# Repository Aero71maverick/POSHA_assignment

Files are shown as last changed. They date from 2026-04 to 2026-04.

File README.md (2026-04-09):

# POSHA Systems Engineering Internship Assignment

**Kunal Paroda** · Roll No: 24B0071  
2nd Year, B.Tech. Aerospace Engineering — IIT Bombay  
Submitted to: POSHA Engineering Team · April 9, 2026

---

## Overview

This repository contains the complete submission for the POSHA Systems Engineering internship assignment, covering three interconnected tasks around servo motor testing, reliability analysis, and robot system design.

| Task | Title |
|---|---|
| Task 1 | Servo Motor QC Jig Design |
| Task 2 | Servo System Reliability & Safety Analysis |
| Task 3 | POSHA System Design Improvements |

---

## Task 1: Servo Motor QC Jig Design

A custom quality-control test jig designed to characterise servo motors — primarily the **Dynamixel XL430-W250-T** — across their full operating envelope: stall torque, no-load speed, efficiency, and current draw at multiple supply voltages.

### Key Design Decisions

- **Target servo:** Dynamixel XL430-W250-T (1.5 N·m stall @ 12 V, 4096 counts/rev absolute encoder, TTL serial bus)
- **Load mechanism:** JGA25-370 DC gear motor with PI current-control loop for precise, commanded torque
- **Frame:** Aluminium 2020 T-slot extrusion (vs. DIN rail) — adjustable, corrosion-resistant, handles stall reaction loads
- **Torque measurement:** Dual load cells (HX711, 24-bit ADC) in a differential configuration that cancels gravitational bias
- **Speed/position:** AS5600 magnetic rotary encoder (12-bit, contactless, I²C)
- **Controller:** Arduino Uno (5 V native — avoids 3.3 V compatibility issues with HX711, ACS712, and servo signal lines)

### CAD Model & Assembly

The full jig was designed in **Fusion 360** as a parametric, jointed assembly. All components are linked by kinematic joints — not just static positions — so the gear mesh, encoder sweep, and reaction arm deflection can all be verified in simulation before physical assembly.

**📹 CAD Joint Motion Video** — click to watch on YouTube:

Fusion 360 Kinematic Demo (https://youtu.be/AN1cJzH8ZRU)
*Full kinematic chain: gear mesh → encoder magnet sweep → load cell arms deflecting.*

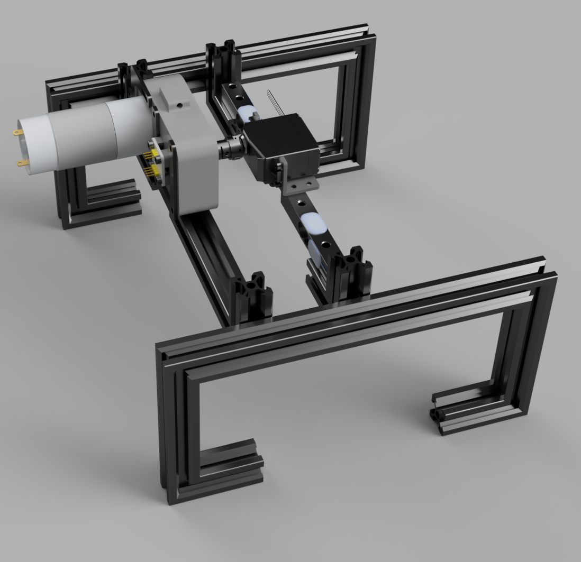
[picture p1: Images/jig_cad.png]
Jig Assembly Isometric

*Full jig assembly at nominal position.*

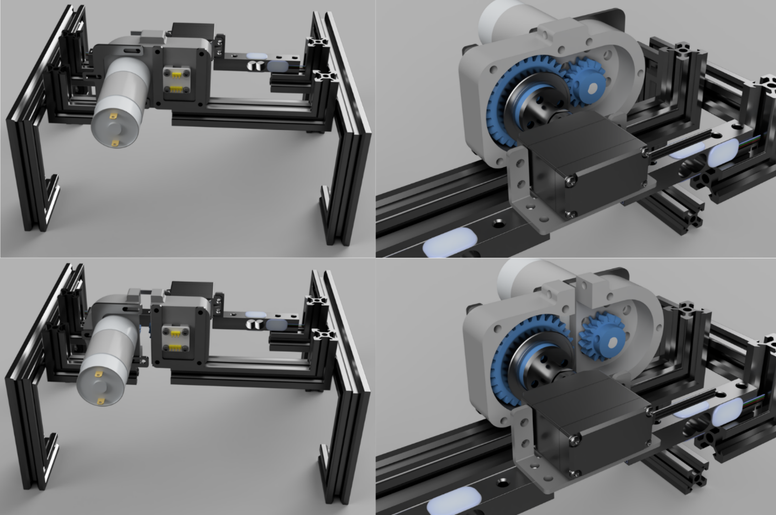
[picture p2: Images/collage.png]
No-Load Configuration

*Motor-side gearbox half disengaged — no-load test configuration.*

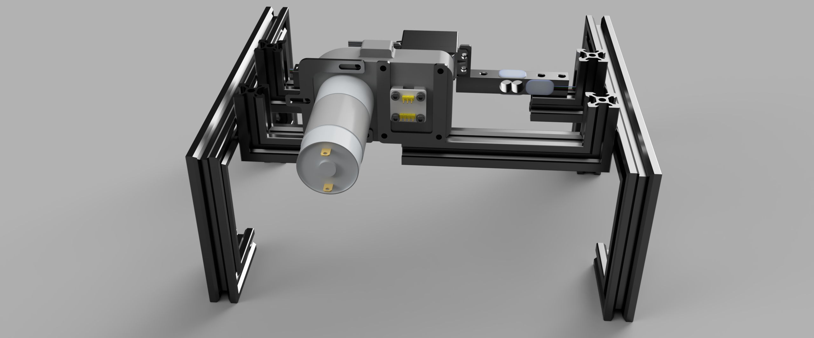
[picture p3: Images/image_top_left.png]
Top Left View

*Top-left view of jig assembly.*

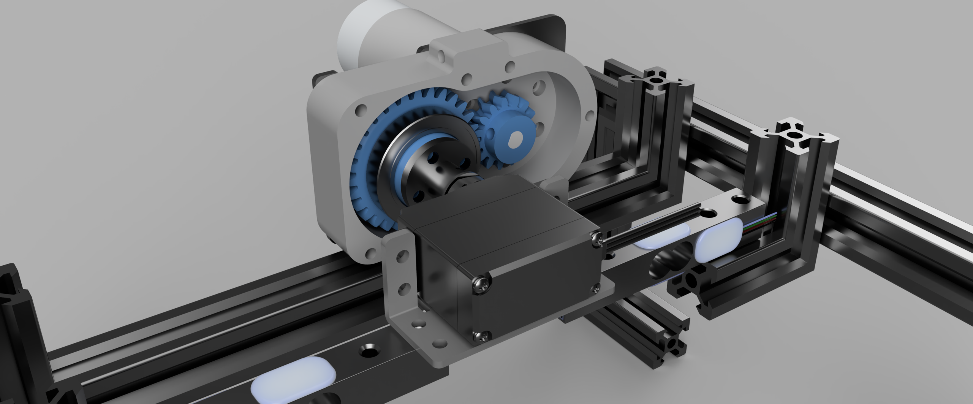
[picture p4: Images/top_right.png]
Top Right View

*Top-right view of jig assembly.*

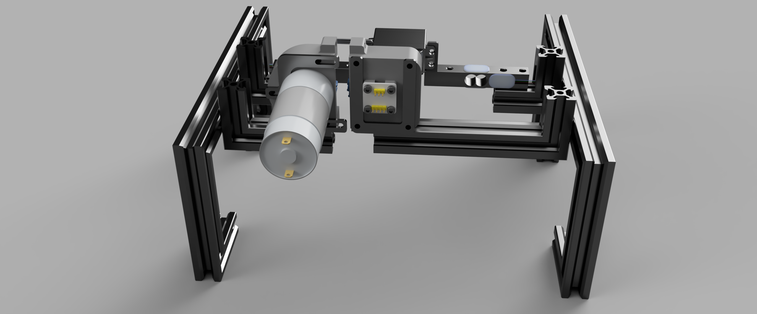
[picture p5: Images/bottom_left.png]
Bottom Left View

*Bottom-left view of jig assembly.*

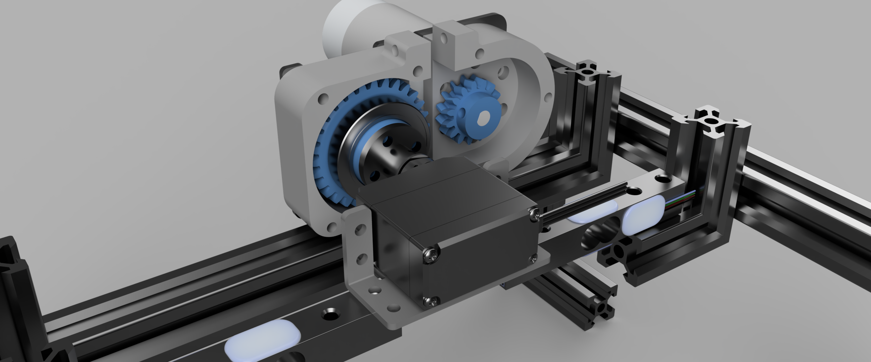
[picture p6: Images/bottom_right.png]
Bottom Right View

*Bottom-right view of jig assembly.*

### FOC Approach Considered and Rejected

A BLDC + field-oriented control approach was sketched (using ODrive/VESC) that would have swept the full performance curve autonomously in ~60 seconds. It was rejected on three grounds:

1. **Cost** — ODrive 3.6 alone costs ₹8,000–12,000; the full DC motor + load cell approach costs under ₹3,000
2. **Calibration bootstrap** — Kt of the BLDC still needs a reference load cell to calibrate, eliminating the key advantage
3. **Systematic error** — a mis-tuned FOC loop introduces unobservable torque error; a load cell is an independent physical measurement

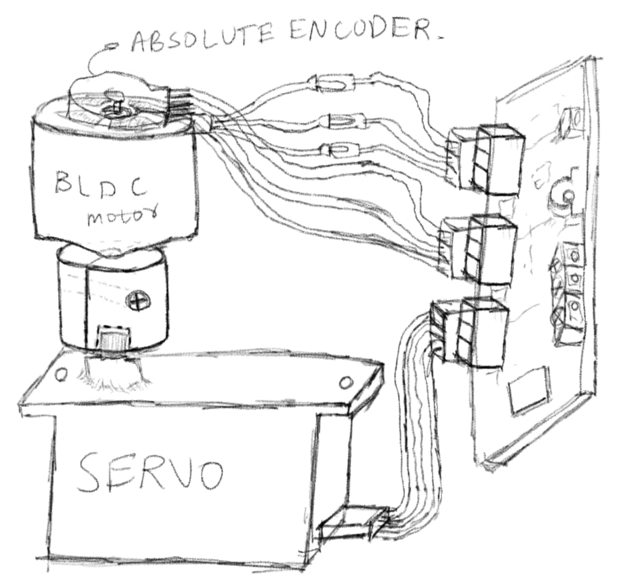
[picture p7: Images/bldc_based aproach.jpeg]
BLDC-Based Approach Sketch

*FOC/BLDC concept sketch — considered and rejected.*

### Electronics

Two separate current measurement strategies are used deliberately:

| Measurement | Sensor | Reason |
|---|---|---|
| Servo current (0–2 A, DUT) | INA219 (shunt, I²C) | High precision, simultaneous voltage → on-chip power calc |
| DC motor current (module) | ACS712 + ADS1115 | Electrically isolated — motor switching noise can't corrupt logic rail |
| DC motor current (PCB) | 2nd INA219 @ 0x41 | Full digital path, eliminates analogue signal routing |

All three I²C devices share SDA/SCL (A4/A5) with unique addresses: AS5600 @ 0x36, INA219 @ 0x40, ADS1115 @ 0x48.

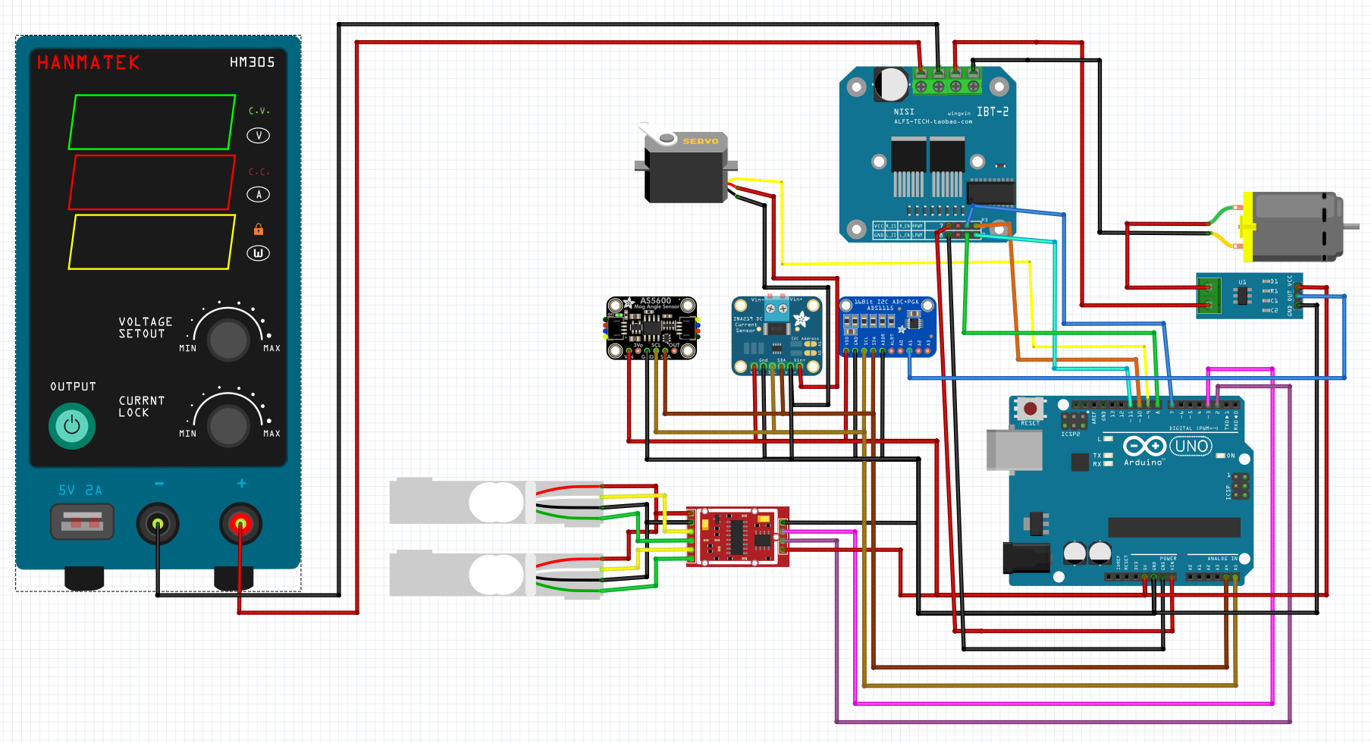
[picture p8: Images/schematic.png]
Wiring Schematic

*Module-based wiring schematic.*

### Firmware

Two firmware variants are provided:

- **`Codes/posha_qc_module.ino`** — Arduino Uno with all breakout modules (ACS712 + ADS1115 for motor current)
- **`Codes/posha_qc_pcb.ino`** — ATmega328P with discrete ICs (dual INA219, fully digital)

Both stream a timestamped CSV over Serial at 20 Hz:

```
t_ms, enc_raw, speed_dps, F1_N, F2_N, torque_Nm, servo_mA, servo_mV, motor_A, tau_cmd_Nm
```

The DC motor torque control loop uses a **PI current controller** (Kp = 8.0, Ki = 0.5) with anti-windup. The outer sweep advances the torque setpoint by 0.05 N·m every 500 ms; the inner loop converges in under 200 ms.

### Bill of Materials

Total build cost (module version, excluding Dynamixel DUT): **≈ ₹4,550**

| Item | Qty | Unit (INR) |
|---|-----|---|
| DS3218 servo (DUT proxy) | 1 | ₹900 |
| JGA25-370 DC gear motor | 1 | ₹450 |
| 2020 extrusion, 500 mm × 4 | 4 | ₹120 |
| 50 kg load cells (matched pair) | 2 | ₹180 |
| HX711 24-bit ADC module | 1 | ₹80 |
| AS5600 encoder module | 1 | ₹150 |
| INA219 module | 1 | ₹80 |
| ACS712 (5 A) module | 1 | ₹70 |
| ADS1115 16-bit ADC | 1 | ₹150 |
| Arduino Uno R3 | 1 | ₹500 |
| BTS7960 H-bridge | 1 | ₹180 |
| 12 V 5 A PSU | 1 | ₹600 |
| 3D-printed parts (PETG) | — | ₹360 |
| Hardware, wiring, consumables | — | ₹510 |

PCB upgrade path (replacing breakout modules): **≈ ₹1,000 additional**

### Calibration

Load cells are calibrated using slotted disc weights (100 g → 2000 g) and a least-squares regression:

$$\text{scale} = \frac{\sum (R_i - \bar{R})(F_i - \bar{F})}{\sum (R_i - \bar{R})^2}$$

Linearity is verified with a one-sample t-test (α = 0.05, n = 5, t_crit = 2.776). Scale factors are stored in EEPROM.

---

## Task 2: Servo System Reliability & Safety

### Failure Modes

| Failure Mode | Root Cause | Detection on Jig | Mitigation |
|---|---|---|---|
| Position sensor wear | Potentiometer wiper erosion | Jitter / dead spots in position output | Magnetic encoder (Dynamixel XL430) |
| Motor winding burnout | Sustained stall current | ↑ no-load current, ↓ stall torque | Stall watchdog (200 ms timeout) |
| Gear backlash | Plastic tooth surface deformation | Hysteresis in oscillation test (> 0.5°) | Metal gear upgrade |
| PWM noise corruption | Commutator switching EMI | Erratic position steps | Shielded cable + 100 nF bypass cap |
| Voltage rail droop | Simultaneous servo actuation | Voltage dip at connector | 470–1000 µF bulk cap per connector |

### Debugging Flow

1. **Isolate mechanically** — run in free air; problem disappears → mechanical binding in robot
2. **Check signal** — oscilloscope on signal pin; noise present → cable routing or shielding
3. **Check supply voltage under load** — > 0.5 V drop → cable too thin or missing bulk cap
4. **Check internal sensors** — no-load current vs. datasheet; elevated → shorted winding turn
5. **Check backlash on jig** — oscillation test between ±5° target angles

### Improvement Suggestions

- **Metal output gears** for any joint running near stall repeatedly (brass/steel yield strength ~10× ABS)
- **470 µF bulk capacitor** at each servo connector
- **Stall watchdog in firmware** — cut torque if position error > threshold for > 200 ms
- **PTC resettable fuse** on each servo power line
- **Migrate to Dynamixel TTL serial** — eliminates PWM noise sensitivity entirely; adds real-time position, velocity, current, and temperature telemetry

---

## Task 3: POSHA System Design Improvements

### Reducing Cooking Time

| Technique | Mechanism | Implementation cost |
|---|---|---|
| **Temperature overshoot** | Pre-store thermal energy before liquid addition; faster phase transition | Software only (thermal model + recipe scheduler) |
| **Pre-heat before user confirms** | Begin heating as soon as recipe is selected | Recipe parser + UI confirmation prompt |
| **Overlap dispense + heating** | Dispense water/stock while heating to next setpoint | Recipe-specific flag for temperature-sensitive ingredients |
| **Torque-based stir frequency** | Motor current = resistance proxy; stir only when needed | Monitor stirring motor current; adaptive threshold |

### Physical & UX Improvements

**Spice dispenser:**
- Single-use sealed cartridges (solenoid/cam puncture) — eliminates cross-contamination and wash cycles
- Alternative: vibratory feeder + load cell for closed-loop mass dispensing (standard in pharmaceutical manufacturing)

**Accessibility:**
- All user interfaces at hip-to-chest height
- Front-loading spice drawer (printer tray style) with positive click latch
- Split-unit architecture — computation/power electronics shelf-mounted separately from the cooking module (same principle as split-system AC)
- Direct tap connection for water inlet, eliminating manual tank fills

**Adaptive recipe learning:**
- Log actual time-to-temperature for each thermal milestone
- Compare against recipe nominal timing
- Adjust preheat and overshoot parameters for subsequent runs
- After 3–4 runs: kitchen-specific thermal model (ambient temperature, altitude, vessel condition)
- Runs entirely on-device — no cloud connectivity required

---

## Repository Structure

```
posha-internship/
├── README.md
├── FInal_submission.pdf              # Full written report
├── CAD_files/
│   ├── POSHA.f3z                     # Fusion 360 full assembly (POSHA robot)
│   └── QC_jig_static.step            # Static STEP export of QC jig assembly
├── Codes/
│   ├── posha_qc_module.ino           # Arduino Uno + breakout modules firmware
│   └── posha_qc_pcb.ino              # ATmega328P + discrete ICs firmware
├── Images/
│   ├── jig_cad.png                   # Full jig assembly isometric
│   ├── collage.png                   # No-load configuration
│   ├── image_top_left.png            # Jig top-left view
│   ├── top_right.png                 # Jig top-right view
│   ├── bottom_left.png               # Jig bottom-left view
│   ├── bottom_right.png              # Jig bottom-right view
│   ├── schematic.png                 # Module-based wiring schematic
│   └── bldc_based aproach.jpeg       # FOC/BLDC concept sketch
├── Videos/
│   └── freecompress-POSHA_fusion.mp4 # Fusion 360 kinematic demo (also on YouTube: https://youtu.be/AN1cJzH8ZRU)
└── schematic/
    └── Posha_submission_schematic.fzz # Fritzing schematic source file
```

---

## How to Run the Jig

1. **Build the frame** — assemble 2020 extrusion with corner brackets; mount servo, gearbox, and load cells
2. **Print parts** — export STLs from Fusion 360; print in PETG at ≥ 40% infill
3. **Wire electronics** — follow schematic in `Images/schematic.png`; verify I²C addresses (AS5600 @ 0x36, INA219 @ 0x40, ADS1115 @ 0x48) before first run
4. **Calibrate** — run the tare routine; hang weights 100 g → 2000 g; store scale factors in EEPROM
5. **No-load test** — disengage motor-side gearbox half; run firmware; verify speed curve vs. OEM
6. **Load sweep** — re-engage gearbox; firmware auto-sweeps 0 → 1.5 N·m in 0.05 N·m steps; export CSV
7. **Analyse** — plot torque vs. speed, torque vs. current, torque vs. efficiency; compare against OEM curves

---

## Notes

- PCB layout was not completed within the assignment window; the module-based implementation is fully functional
- 3D-printed STLs export directly from the Fusion 360 assembly — no additional CAD preparation needed
- The FOC/BLDC approach was considered and documented but set aside on cost and calibration grounds — see Section 1.2 of the report

---

*IIT Bombay · POSHA Assignment · April 2026*

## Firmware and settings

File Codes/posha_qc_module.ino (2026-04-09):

#include <Wire.h>
#include <HX711.h>
#include <Adafruit_INA219.h>
#include <Adafruit_ADS1X15.h>

// --- Pin definitions ---
#define SERVO_PIN   9
#define RPWM       10   // BTS7960 forward PWM
#define LPWM       11   // BTS7960 reverse PWM
#define R_EN        7
#define L_EN        8
#define HX_DT       3
#define HX_SCK      2

// --- I2C devices ---
Adafruit_INA219 ina219(0x40);  // servo current
Adafruit_ADS1115 ads;          // ACS712 via ADS1115

// --- HX711 ---
HX711 cells;

// --- Calibration ---
float cell_a_scale  = 1.0;   // set during calibration
float cell_b_scale  = 1.0;
float cell_a_offset = 0.0;
float cell_b_offset = 0.0;
const float ARM_R   = 0.05;  // moment arm in metres

// --- Torque control (PI current loop) ---
float torque_setpoint_Nm = 0.0;
const float KT_MOTOR     = 0.025; // JGA25-370 approx Kt (N.m/A)
const float Kp_I         = 8.0;
const float Ki_I         = 0.5;
float integral_error     = 0.0;
const float I_MAX        = 3.5;   // max motor current A

// --- AS5600 raw register read ---
uint16_t readAS5600() {
  Wire.beginTransmission(0x36);
  Wire.write(0x0C);
  Wire.endTransmission(false);
  Wire.requestFrom(0x36, 2);
  uint16_t hi = Wire.read();
  uint16_t lo = Wire.read();
  return ((hi << 8) | lo) & 0x0FFF;
}

// --- Motor PWM output ---
void setMotorPwm(int pwm) {
  if (pwm >= 0) {
    analogWrite(RPWM, constrain(pwm, 0, 255));
    analogWrite(LPWM, 0);
  } else {
    analogWrite(RPWM, 0);
    analogWrite(LPWM, constrain(-pwm, 0, 255));
  }
}

// --- PI current controller for load motor ---
// Call at ~20 Hz. Returns actual motor current in A.
float runMotorCurrentPI(float dt) {
  // Read motor current from ACS712 via ADS1115
  int16_t raw = ads.readADC_SingleEnded(0);
  float acs_V = raw * 0.0001875f;            // 6.144V FSR / 32768
  float I_actual = (acs_V - 2.5f) / 0.185f; // ACS712-05B: 185 mV/A, midpoint 2.5V

  float I_cmd = torque_setpoint_Nm / KT_MOTOR;
  I_cmd = constrain(I_cmd, 0.0f, I_MAX);

  float err = I_cmd - I_actual;
  integral_error += err * dt;
  integral_error = constrain(integral_error, -50.0f, 50.0f); // anti-windup

  float u = Kp_I * err + Ki_I * integral_error;
  int pwm_out = (int)constrain(u, -255, 255);
  setMotorPwm(pwm_out);

  return I_actual;
}

void setup() {
  Serial.begin(115200);
  Wire.begin();

  pinMode(SERVO_PIN, OUTPUT);
  pinMode(RPWM, OUTPUT); pinMode(LPWM, OUTPUT);
  pinMode(R_EN, OUTPUT); pinMode(L_EN, OUTPUT);
  digitalWrite(R_EN, HIGH);
  digitalWrite(L_EN, HIGH);

  cells.begin(HX_DT, HX_SCK);
  ina219.begin();
  ads.setGain(GAIN_ONE);
  ads.begin();

  // Tare both channels
  cells.set_gain(128);
  cell_a_offset = cells.read_average(20);
  cells.set_gain(32);
  cell_b_offset = cells.read_average(20);

  Serial.println("t_ms,enc_raw,speed_dps,F1_N,F2_N,torque_Nm,"
                 "servo_mA,servo_mV,motor_A,tau_cmd_Nm");
}

float prevAngle = 0;
unsigned long prevTime = 0;
unsigned long lastSweepStep = 0;
const float SWEEP_STEP = 0.05;     // N.m per step
const float SWEEP_MAX  = 1.5;      // max torque
const unsigned long STEP_INTERVAL = 500; // ms between steps

void loop() {
  unsigned long now = millis();
  float dt = (now - prevTime) / 1000.0f;

  // --- Encoder ---
  uint16_t enc_raw = readAS5600();
  float angle = enc_raw * (360.0f / 4096.0f);
  float speed_dps = 0;
  if (prevTime != 0 && dt > 0) {
    float da = angle - prevAngle;
    if (da >  180) da -= 360;
    if (da < -180) da += 360;
    speed_dps = da / dt;
  }
  prevAngle = angle;
  prevTime  = now;

  // --- Load cells ---
  cells.set_gain(128); float ra = cells.read();
  cells.set_gain(32);  float rb = cells.read();
  float F1 = (ra - cell_a_offset) * cell_a_scale;
  float F2 = (rb - cell_b_offset) * cell_b_scale;
  float torque_meas = (F1 - F2) * ARM_R;

  // --- Servo current ---
  float servo_mA = ina219.getCurrent_mA();
  float servo_mV = ina219.getBusVoltage_V() * 1000.0f;

  // --- Motor PI current loop ---
  float motor_A = runMotorCurrentPI(dt);

  // --- Torque sweep (advances setpoint every STEP_INTERVAL ms) ---
  if (now - lastSweepStep > STEP_INTERVAL) {
    torque_setpoint_Nm += SWEEP_STEP;
    if (torque_setpoint_Nm > SWEEP_MAX) torque_setpoint_Nm = SWEEP_MAX;
    lastSweepStep = now;
  }

  // --- CSV output ---
  Serial.print(now);               Serial.print(',');
  Serial.print(enc_raw);           Serial.print(',');
  Serial.print(speed_dps, 2);      Serial.print(',');
  Serial.print(F1, 4);             Serial.print(',');
  Serial.print(F2, 4);             Serial.print(',');
  Serial.print(torque_meas, 4);    Serial.print(',');
  Serial.print(servo_mA, 2);       Serial.print(',');
  Serial.print(servo_mV, 1);       Serial.print(',');
  Serial.print(motor_A, 3);        Serial.print(',');
  Serial.println(torque_setpoint_Nm, 3);

  delay(50); // 20 Hz sample rate
}

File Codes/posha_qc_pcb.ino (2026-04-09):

#include <Wire.h>
#include <HX711.h>
#include <Adafruit_INA219.h>

// PCB: INA219 at 0x40 = servo, 0x41 = DC motor (A0 pin tied to VCC)
Adafruit_INA219 ina_servo(0x40);
Adafruit_INA219 ina_motor(0x41);

#define HX_DT  3
#define HX_SCK 2
#define SERVO_PIN 9
#define RPWM 10
#define LPWM 11
#define R_EN  7
#define L_EN  8

HX711 cells;
float a_scale = 1.0, b_scale = 1.0, a_off = 0, b_off = 0;
const float ARM_R = 0.05;

// PI parameters (same as module version)
float tau_cmd = 0.0;
const float KT_M = 0.025;
const float Kp   = 8.0, Ki = 0.5;
float iErr = 0.0;
const float I_MAX = 3.5;

uint16_t readAS5600() {
  Wire.beginTransmission(0x36);
  Wire.write(0x0C);
  Wire.endTransmission(false);
  Wire.requestFrom(0x36, 2);
  return (((uint16_t)Wire.read() << 8) | Wire.read()) & 0x0FFF;
}

void setMotorPwm(int p) {
  if (p >= 0) { analogWrite(RPWM, constrain(p,0,255)); analogWrite(LPWM,0); }
  else         { analogWrite(RPWM,0); analogWrite(LPWM, constrain(-p,0,255)); }
}

float runPI(float dt) {
  float I_act = ina_motor.getCurrent_mA() / 1000.0f; // convert to A
  float I_cmd = constrain(tau_cmd / KT_M, 0.0f, I_MAX);
  float err = I_cmd - I_act;
  iErr = constrain(iErr + err * dt, -50.0f, 50.0f);
  setMotorPwm((int)constrain(Kp * err + Ki * iErr, -255, 255));
  return I_act;
}

void setup() {
  Serial.begin(115200);
  Wire.begin();
  pinMode(SERVO_PIN,OUTPUT);
  pinMode(RPWM,OUTPUT); pinMode(LPWM,OUTPUT);
  pinMode(R_EN,OUTPUT); pinMode(L_EN,OUTPUT);
  digitalWrite(R_EN,HIGH); digitalWrite(L_EN,HIGH);

  cells.begin(HX_DT, HX_SCK);
  ina_servo.begin();
  ina_motor.begin();

  cells.set_gain(128); a_off = cells.read_average(20);
  cells.set_gain(32);  b_off = cells.read_average(20);

  Serial.println("t_ms,enc,dps,F1,F2,tau_meas,sA,smV,mA,mmV,tau_cmd");
}

float pA = 0; unsigned long pT = 0, lastStep = 0;

void loop() {
  unsigned long t = millis();
  float dt = pT ? (t - pT) / 1000.0f : 0.05f;

  uint16_t enc = readAS5600();
  float ang = enc * (360.0f / 4096.0f);
  float dps = 0;
  if (pT) {
    float da = ang - pA;
    if (da > 180) da -= 360; if (da < -180) da += 360;
    dps = da / dt;
  }
  pA = ang; pT = t;

  cells.set_gain(128); float ra = cells.read();
  cells.set_gain(32);  float rb = cells.read();
  float F1  = (ra - a_off) * a_scale;
  float F2  = (rb - b_off) * b_scale;
  float tau = (F1 - F2) * ARM_R;

  float sA  = ina_servo.getCurrent_mA();
  float sV  = ina_servo.getBusVoltage_V() * 1000;
  float mA  = runPI(dt);
  float mV  = ina_motor.getBusVoltage_V() * 1000;

  if (t - lastStep > 500) {
    tau_cmd = min(tau_cmd + 0.05f, 1.5f);
    lastStep = t;
  }

  Serial.print(t);    Serial.print(',');
  Serial.print(enc);  Serial.print(',');
  Serial.print(dps,2);Serial.print(',');
  Serial.print(F1,4); Serial.print(',');
  Serial.print(F2,4); Serial.print(',');
  Serial.print(tau,4);Serial.print(',');
  Serial.print(sA,2); Serial.print(',');
  Serial.print(sV,1); Serial.print(',');
  Serial.print(mA,3); Serial.print(',');
  Serial.print(mV,1); Serial.print(',');
  Serial.println(tau_cmd,3);
  delay(50);
}

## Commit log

2026-04-09 folders added
    [Posha_submission_schematic.fzz]
2026-04-09 Update image paths and add new CAD files section
2026-04-09 Enhance README with video link and wiring details
    Updated the CAD Joint Motion Video section with a clickable thumbnail and improved description. Added details about I²C addresses in the wiring instructions.
